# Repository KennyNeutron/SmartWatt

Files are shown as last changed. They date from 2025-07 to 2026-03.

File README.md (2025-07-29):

# SmartWatt

SmartWatt is a distributed smart energy limiter system designed to help households, boarding houses, and small businesses save on electricity costs. It uses a network of ESP32 microcontrollers and precision sensors to monitor and control multiple outlets, and automatically switches the main power source between grid, solar, or battery backup when a daily energy limit is reached.

## System Architecture

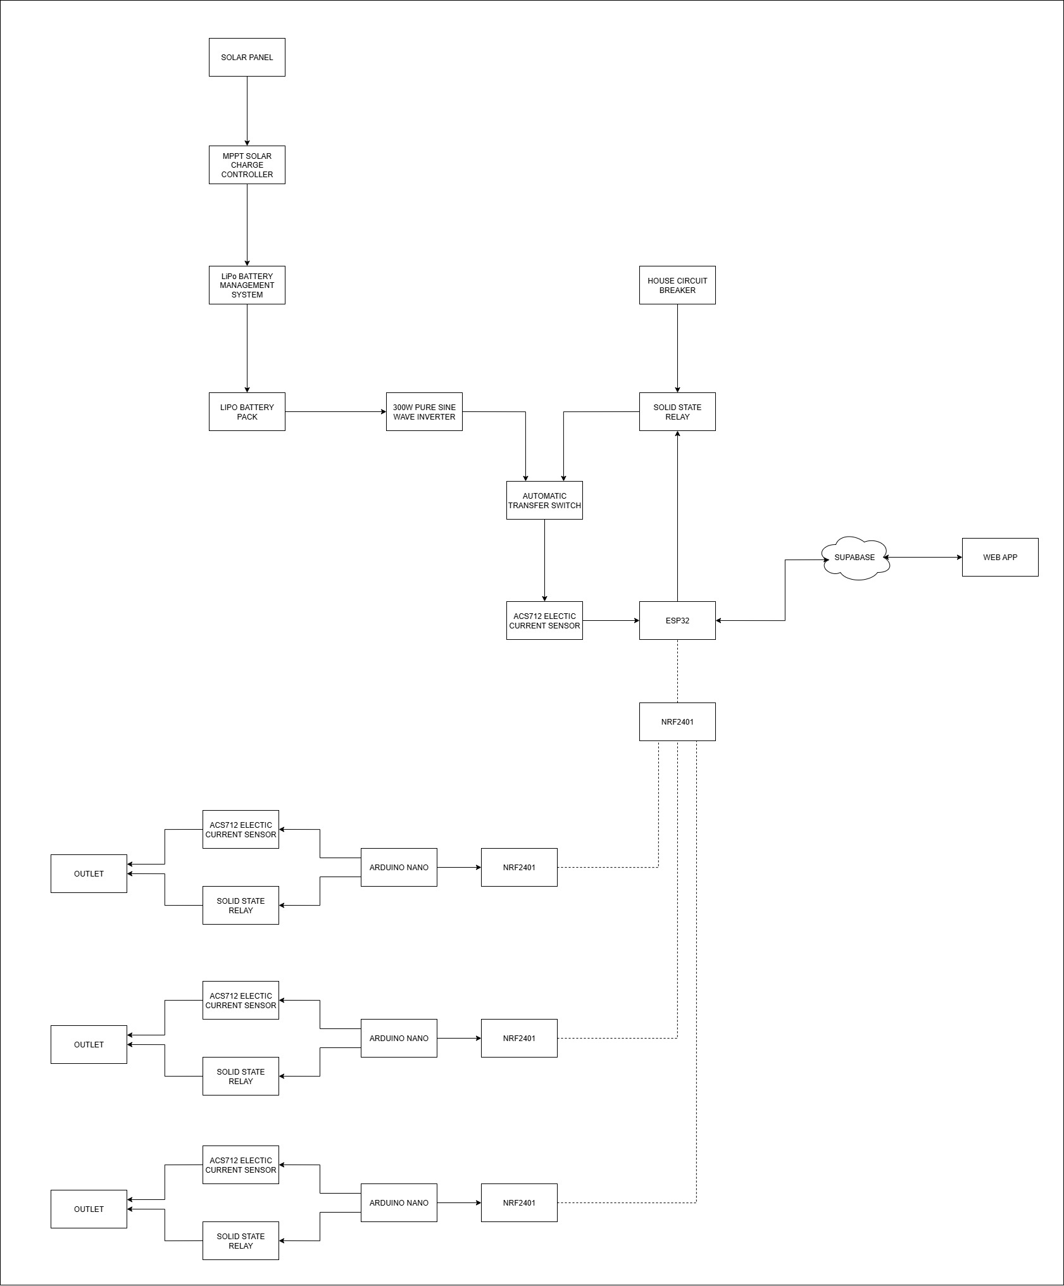
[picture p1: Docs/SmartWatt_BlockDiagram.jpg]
Block Diagram


1. **Solar & Battery Subsystem**

   - **Solar Panel** → **MPPT Solar Charge Controller** → **LiPo Battery Management System** → **LiPo Battery Pack**
   - **Pure Sine Wave Inverter** (300W) converts battery DC to AC.
   - **Automatic Transfer Switch (ATS)** chooses between inverter output and grid power.
   - **Solid State Relay (SSR)** connects the selected source to the house circuit breaker.

2. **Master Controller (ESP32)**

   - Reads total system current via ACS712 sensor.
   - Communicates daily energy usage and user settings to Supabase.
   - Forwards control commands to distributed outlet controllers via ESP-NOW.

3. **Distributed Outlet Controllers** (one per outlet)

   - **ESP32** monitors outlet current with an ACS712 sensor.
   - Controls outlet power via a dedicated SSR.
   - Joins the ESP-NOW mesh network to report usage and receive limit flags from the master controller.

4. **Cloud & Web Dashboard**
   - **Supabase** stores user accounts, settings, and energy logs.
   - **Web App** (hosted static site) provides secure login, live consumption dashboard, manual override, and monthly savings reports.

## Features

- **Per-Outlet Monitoring & Control**  
  Track and limit energy consumption at individual outlets.

- **Automatic Source Switching**  
  When the total daily kWh limit is reached, ATS and SSRs safely switch to solar/battery backup.

- **Distributed ESP-NOW Network**  
  Low-latency communication between the master ESP32 and outlet controllers without Wi‑Fi.

- **Secure Cloud Storage**  
  User profiles, limits, and usage logs are managed via Supabase.

- **Web-Based Dashboard**
  - Secure login
  - Set or adjust daily kWh limit
  - Real-time system and per‑outlet consumption
  - Manual override of grid or solar/battery source
  - Monthly savings report

## Hardware Components

- Solar panel and MPPT charge controller
- LiPo battery pack with BMS
- 300W pure sine wave inverter
- Automatic Transfer Switch (ATS) module
- Solid State Relays (SSRs) for system and each outlet
- ACS712 current sensors (system and per outlet)
- ESP32 microcontrollers (master and distributed controllers)
- Standard house wiring and circuit breaker panel

## Software & Cloud

- **ESP32 Firmware**

  - Master node: system monitoring, Supabase sync, ESP-NOW master
  - Outlet nodes: per-outlet monitoring and SSR control

- **Supabase**

  - PostgreSQL database for users, settings, and logs
  - Auth for secure login
  - Storage (optional) for graphs or logs

- **Web App**
  - Static React (or framework of choice) application
  - Connects to Supabase via its JavaScript SDK

## Installation & Deployment

1. Flash ESP32 firmware to master and outlet controllers.
2. Assemble hardware following the block diagram.
3. Configure Supabase project:
   - Create tables: `users`, `settings`, `system_logs`, `outlet_logs`.
   - Set up Auth and policies.
4. Deploy web app to any static host (Netlify, Vercel, GitHub Pages).
5. Enter Supabase project URL and key in the web app configuration.

## Configuration

- **Daily kWh Limit**: Set in the Settings page of the dashboard.
- **Manual Override**: Select grid or solar/battery source from the live dashboard.
- **Outlet Enable/Disable**: Toggle individual outlets on the dashboard.

## Contributing

1. Fork the repository.
2. Create a branch (`git checkout -b feature/your-feature`).
3. Commit changes (`git commit -m "Add feature"`).
4. Push (`git push origin feature/your-feature`).
5. Open a Pull Request.

## License

This project is licensed under the [MIT License](LICENSE).

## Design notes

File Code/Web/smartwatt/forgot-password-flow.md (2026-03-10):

# SmartWatt - Forgot Password Flow

This document outlines the architecture and user flow for the "Forgot Password" feature implemented in the SmartWatt web application.

## Overview

We use **Supabase Authentication** to handle the secure password reset process. Instead of emailing a reset link that the user must click (which can be problematic with certain email clients or if opened on a different device), we utilize an **OTP (One-Time Password) / 6-digit PIN code** flow.

When the OTP is verified successfully, Supabase securely logs the user in, giving them the necessary session to update their password on the `/reset-password` page.

## Detailed Flow

### 1. Request OTP (Email Step)

- **Location:** `/forgot-password` (Step 1)
- **Action:** The user enters their email address and clicks "Send Code".
- **Under the hood:**
  The client component calls `supabase.auth.signInWithOtp()` with the `shouldCreateUser: false` option. This ensures that a 6-digit OTP is sent only if the email belongs to an existing registered user.
- **UI Feedback:** A success message "Code sent! Check your email." is displayed, and the UI shifts to the Verification step.

### 2. Verify OTP (Verification Step)

- **Location:** `/forgot-password` (Step 2)
- **Action:** The user enters the 6-digit code received in their email.
- **Under the hood:**
  The component calls `supabase.auth.verifyOtp({ email, token: otp, type: "email" })`.
  If the OTP matches, the Supabase client successfully authenticates the user and creates an active session.
- **UI Feedback:** Upon success, the UI displays "Verified! Redirecting..." and routes the user to `/reset-password`.

### 3. Set New Password

- **Location:** `/reset-password`
- **Prerequisite:** The user must be authenticated (which they are, having just verified the OTP).
- **Action:** The user enters a new password and confirms it.
- **Under the hood:**
  The page calls `supabase.auth.updateUser({ password: newPassword })` to securely overwrite the existing password.
- **UI Feedback:** The user receives a success message ("Password updated successfully! Redirecting...") and is redirected to the `/login` page, or straight to `/home` depending on internal application logic.

## Why OTP instead of a Magic Link?

1. **Seamless Cross-Device Experience:** A user can request the code on their mobile app/desktop, check their email on another device, and type the 6-digit code back on the original device without losing their place.
2. **Reduced Email Provider Issues:** Some strict enterprise email clients "pre-fetch" or automatically click links in emails to scan them for malware, which can accidentally consume single-use magic links before the user clicks them.
3. **Better UX:** Keeps the user within the original tab/app rather than bouncing them out to their email client and back in a new tab.

## Relevant Files

- `src/app/forgot-password/page.tsx` - Email and OTP request & verification UI.
- `src/app/reset-password/page.tsx` - The actual password update component.
- `src/lib/supabase/client.ts` - The Supabase client initialization.

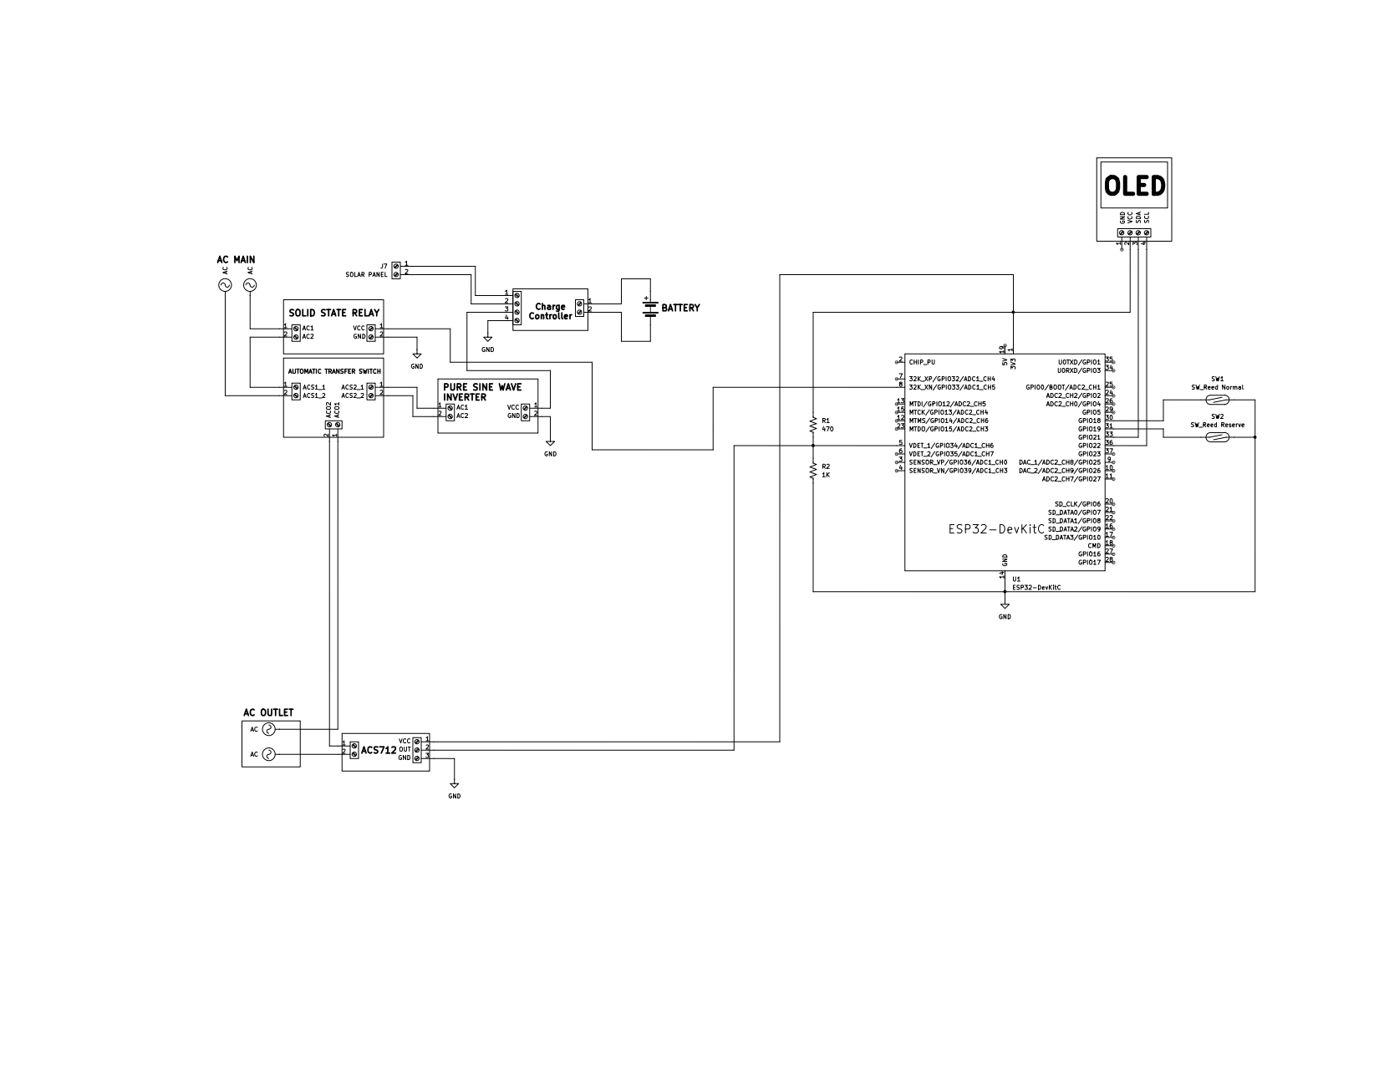
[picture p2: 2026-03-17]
Docs/Diagram V2/Smartwatt Schematic V2_page-0001.jpg

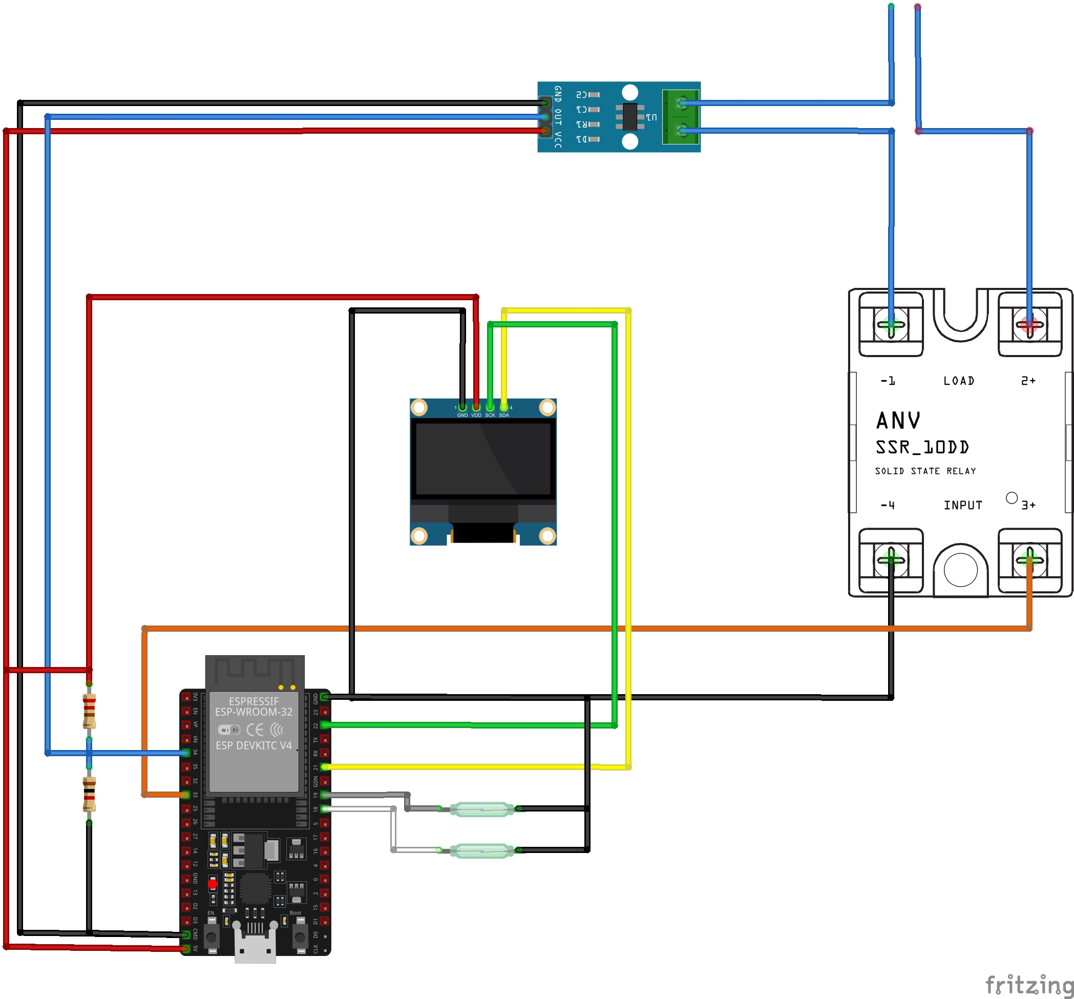
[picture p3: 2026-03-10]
Docs/Diagram V2/SmartWatt Fritzing V2_bb.jpg

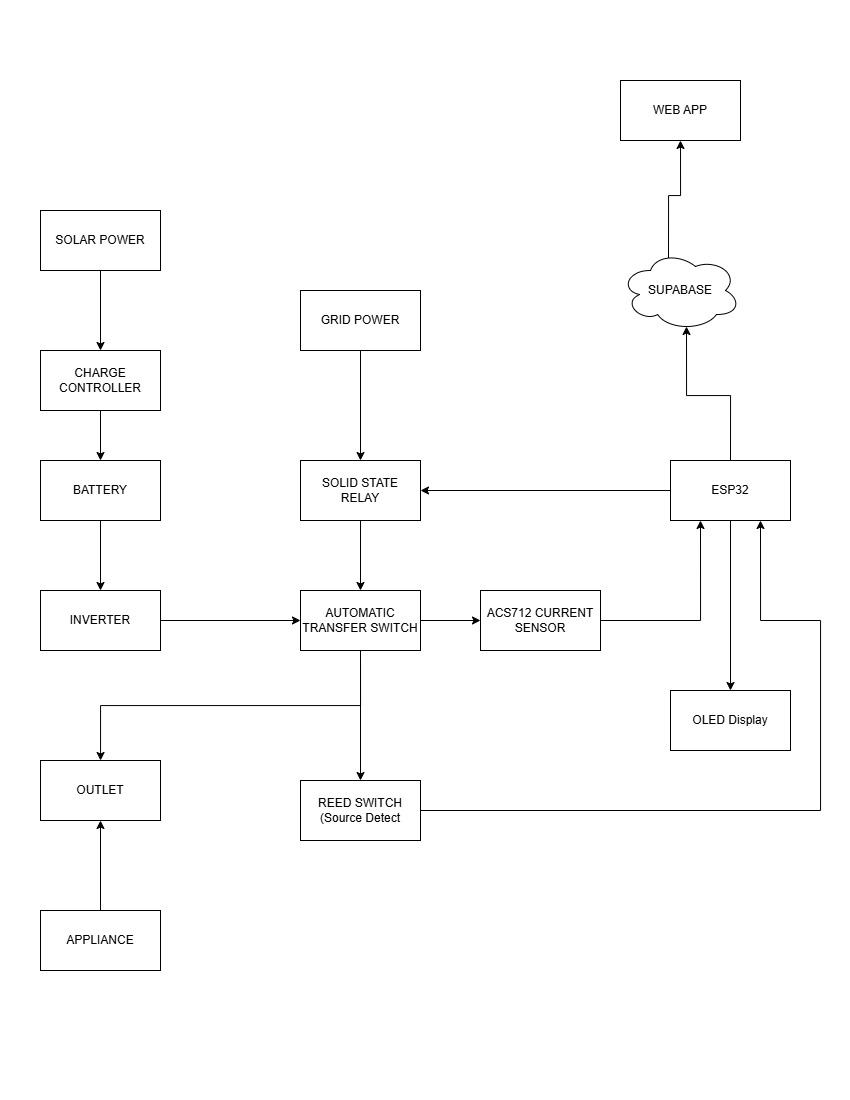
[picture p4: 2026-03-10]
Docs/Diagram V2/Smartwatt Block Diagram V2.jpg

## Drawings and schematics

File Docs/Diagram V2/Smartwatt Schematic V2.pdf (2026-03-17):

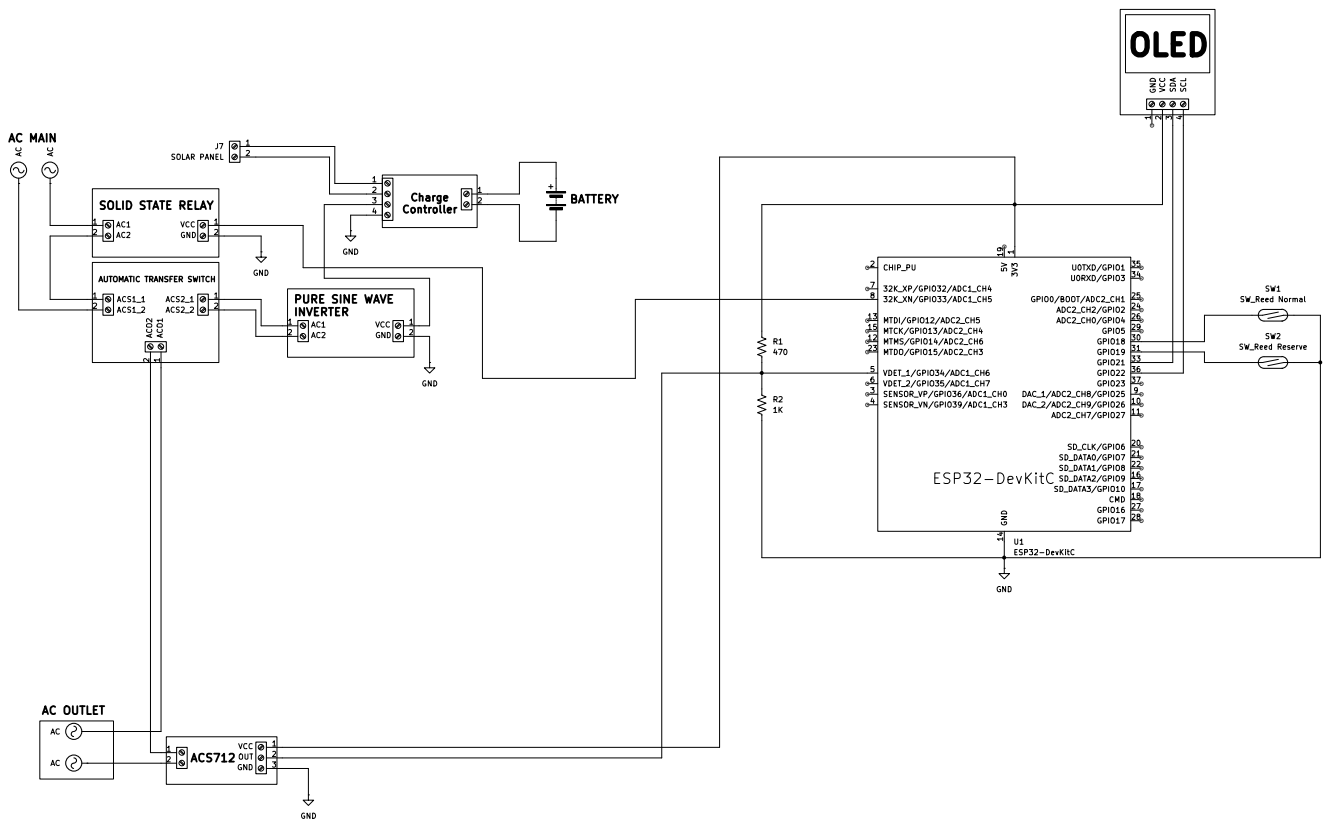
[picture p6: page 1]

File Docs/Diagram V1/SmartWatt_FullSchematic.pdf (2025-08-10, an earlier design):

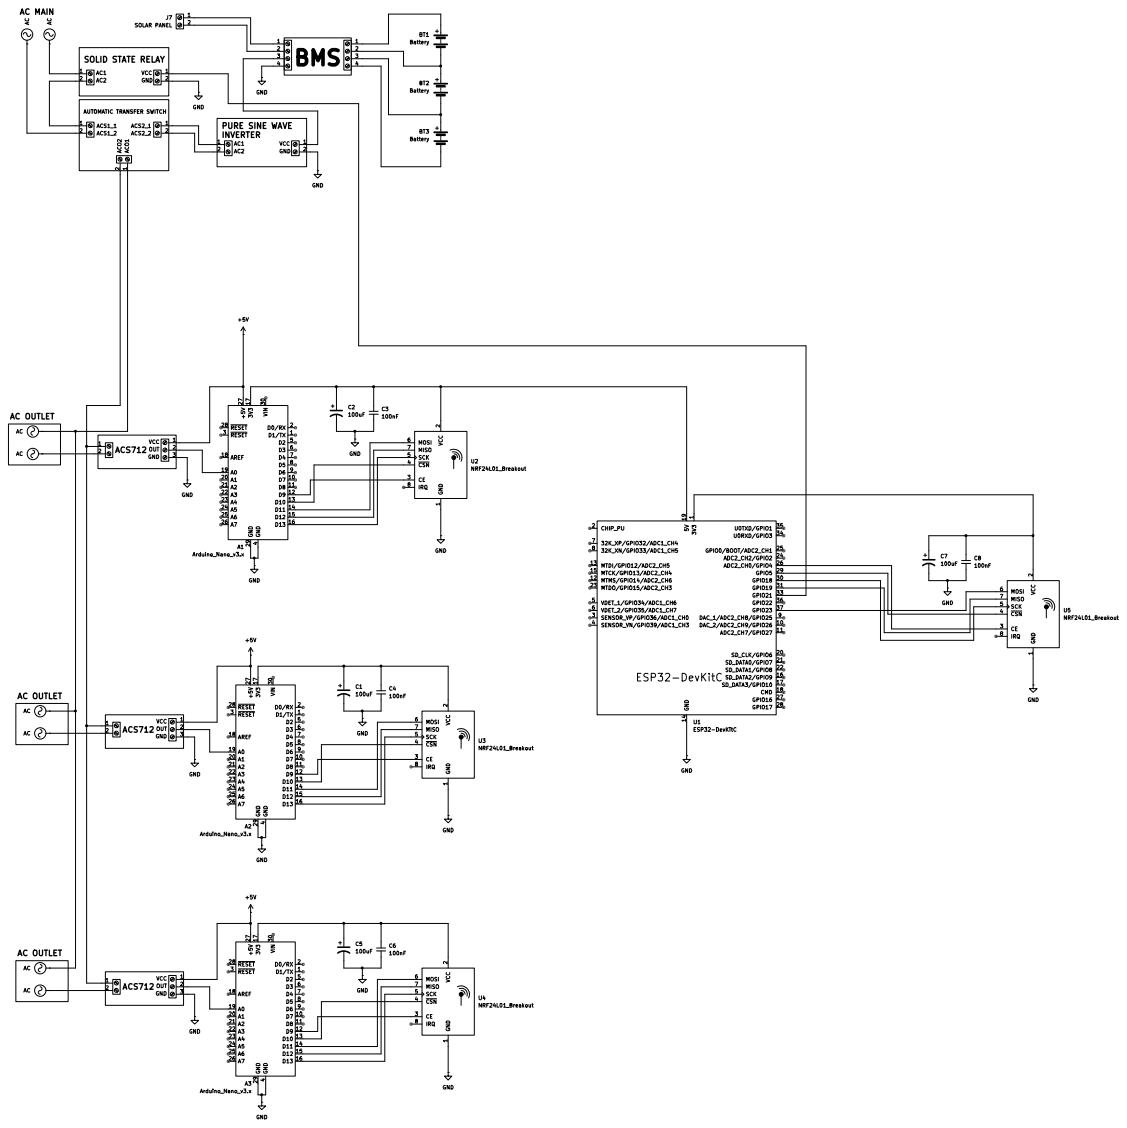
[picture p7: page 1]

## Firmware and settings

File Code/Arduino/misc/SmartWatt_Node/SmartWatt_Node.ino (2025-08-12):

/*
  SmartWatt Node v1.0.0
  Environment:           Arduino Nano/Uno
  Author:                
  Date Started:          2025-08-11
  Pin Usage:
    Current Sensor (ACS712):
      OUT   - A0 (Analog Pin 0)
      VCC   - 5V
      GND   - GND
    NRF24L01:
      CE    - GPIO9
      CSN   - GPIO10
      SCK   - GPIO13
      MOSI  - GPIO11
      MISO  - GPIO12
      VCC   - 3.3V
      GND   - GND
  Board Settings:
    Board:                     Arduino Nano
    Port:                      COM3
    Processor:                 ATmega328P (Old Bootloader)
    Programmer:                AVRISP mkII
  Features:
    - Current measurement with ACS712 sensor
    - Automatic offset calibration
    - Threshold filtering (ignores values < 0.1A)
    - Current display in mA and A (2 decimal places)
    - Wireless data transmission via NRF24L01
    - Real-time serial monitoring
*/

#include <SPI.h>
#include <nRF24L01.h>
#include <RF24.h>

// CE and CSN pins
RF24 NRF(9, 10);  // CE, CSN
byte address[6] = "SWD25";

// Data structure matching SmartWatt Node
struct __attribute__((packed)) SmartWatt_Data {
  uint8_t deviceID;
  uint16_t currentConsumption; // Use unsigned for mA
};


SmartWatt_Data smartwattData;

const int sensorPin = A0;
const float sensitivity = 0.066;  // V/A (0.100 for 20A module, 0.066 for 30A, 0.185 for 5A)
const float Vref = 5.0;
const float minCurrentThreshold = 0.1;  // Minimum current threshold to consider valid

float offsetVoltage = 2.5;  // Typical midpoint (sensor output with no current)

void setup() {
  Serial.begin(9600);

  smartwattData.deviceID = 0x01;
  smartwattData.currentConsumption = 0;

  // Debug print
  Serial.print("Device ID: 0x");
  Serial.println(smartwattData.deviceID, HEX);

  // Take an initial reading to determine offset voltage (zero current)
  long sum = 0;
  for (int i = 0; i < 100; i++) {
    sum += analogRead(sensorPin);
    delay(5);
  }
  offsetVoltage = (sum / 100.0) * (Vref / 1023.0);

  Serial.print(F("Calibrated Offset Voltage: "));
  Serial.println(offsetVoltage, 3);

  //Try to initialize NRF module for 5 seconds
  while (!NRF.begin()) {
    Serial.println(F("NRF24L01 Module not responding! Retrying..."));
    delay(1000);
  }
  Serial.println(F("NRF24L01 Module initialized successfully."));

  NRF.setPALevel(RF24_PA_MAX);
  NRF.setDataRate(RF24_250KBPS);
  NRF.openWritingPipe(address);
}

void loop(){
    int rawValue = analogRead(sensorPin);
  float voltage = (rawValue * Vref) / 1023.0;
  float current = (voltage - offsetVoltage) / sensitivity;

  // Apply threshold filter but keep as float
  float processedCurrent = 0.0;
  if (abs(current) >= minCurrentThreshold) {
    processedCurrent = current;  // Keep as float, no rounding
  }

  // Convert to mA using uint16_t and abs()
  smartwattData.currentConsumption = (uint16_t)(abs(processedCurrent) * 1000);

  Serial.print(F("Raw ADC: "));
  Serial.print(rawValue);
  Serial.print(F(" | Voltage: "));
  Serial.print(voltage, 3);
  Serial.print(F(" V | Current: "));
  Serial.print(smartwattData.currentConsumption);
  Serial.print(F(" mA ("));
  Serial.print(smartwattData.currentConsumption / 1000.0, 2);  // Display in A with 2 decimal places
  Serial.println(F(" A)"));

  // Send processed data via NRF
  NRF.write(&smartwattData, sizeof(smartwattData));
  Serial.println("Data sent successfully.");
  delay(1000);
}

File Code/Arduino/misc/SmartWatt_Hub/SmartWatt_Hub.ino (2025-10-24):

/*
  SmartWatt Receiver v1.0.0
  Environment:           ESP32 Dev Module
  Author:                
  Date Started:          2025-08-11
  Pin Usage:
    NRF24L01:
      CE    - GPIO4
      CSN   - GPIO5
      SCK   - GPIO18
      MOSI  - GPIO23
      MISO  - GPIO19
      VCC   - 3.3V
      GND   - GND
  Board Settings:
    Board:                     ESP32 Dev Module
    Port:                      COM3
    CPU Frequency:             240 MHz (WiFi/BT)
    Core Debug Level:          None
    Erase Flash Before Upload: Disabled
    Events Run On:             Core 1
    Flash Frequency:           80 MHz
    Flash Mode:                QIO
    Flash Size:                4 MB (32 Mb)
    JTAG Adapter:              Disabled
    Arduino Runs On:           Core 1
    Partition Scheme:          Default 4 MB w/ SPIFFS (1.2 MB APP / 1.5 MB SPIFFS)
    PSRAM:                     Disabled
    Upload Speed:              921600
    Zigbee Mode:               Disabled
  Features:
    - Wireless data reception via NRF24L01
    - SmartWatt Node data parsing
    - Real-time current monitoring display (2 decimal places)
    - Device ID identification
    - Connection status monitoring
*/

#include <SPI.h>
#include <nRF24L01.h>
#include <RF24.h>
#include <U8g2lib.h>

// NRF24L01 pins for ESP32
RF24 NRF(4, 5);  // CE, CSN
byte address[6] = "SWD25";

U8G2_SH1106_128X64_NONAME_F_HW_I2C u8g2(U8G2_R0, /* reset=*/U8X8_PIN_NONE);

// Data structure matching SmartWatt Node
struct __attribute__((packed)) SmartWatt_Data {
  uint8_t deviceID;
  uint16_t currentConsumption; // Use unsigned for mA
};


SmartWatt_Data smartwattData;

unsigned long lastDataReceived = 0;
const unsigned long dataTimeout = 5000;  // 5 seconds timeout

void setup() {
  Serial.begin(115200);
  u8g2.begin();
  Serial.println("SmartWatt Receiver Starting...");
  Serial.println("===============================");

  // Initialize NRF24L01
  if (!NRF.begin()) {
    Serial.println("ERROR: NRF24L01 Module not responding!");
    while (1) {
      delay(1000);
      Serial.println("Retrying NRF24L01 initialization...");
      if (NRF.begin()) {
        break;
      }
    }
  }
  Serial.println("NRF24L01 Module initialized successfully.");

  // Configure NRF24L01
  NRF.setPALevel(RF24_PA_MAX);
  NRF.setDataRate(RF24_250KBPS);
  NRF.openReadingPipe(0, address);
  NRF.startListening();

  Serial.println("Receiver ready. Waiting for SmartWatt Node data...");
  Serial.println("Format: [Device ID] | Current: XX.XX A | (Raw mA: XXX) | Status");
  Serial.println("=============================================================");
}

void loop() {


  display_Main();

  // Check if data is available
  if (NRF.available()) {
    // Read the data
    NRF.read(&smartwattData, sizeof(smartwattData));
    lastDataReceived = millis();

    // Display device ID
    Serial.print("[0x0");
    Serial.print(smartwattData.deviceID, HEX);

    // Debug: Show raw milliamp value
    Serial.print("] Raw mA: ");
    Serial.println(smartwattData.currentConsumption);
  }

  // Check for communication timeout
  if (millis() - lastDataReceived > dataTimeout && lastDataReceived > 0) {
    Serial.println("WARNING: No data received for 5 seconds!");
    Serial.println("Check SmartWatt Node connection and power.");
    Serial.println("Waiting for data...");
    lastDataReceived = 0;  // Reset to avoid repeated warnings
  }

  delay(100);  // Small delay to prevent overwhelming serial output
}

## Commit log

2025-08-05 added files for the schematic/wiring diagram of the system (by parts)
    [SmartWatt.fzz]
2025-08-10 added KiCAD files for the full schematic diagram of the project (as one)
    [SmarWatt.kicad_pcb, SmarWatt.kicad_sch]
2025-08-10 updated fritzing files and block diagram for the comm adjustment to NRF24L01 from ESPNOW
    [SmartWatt.fzz]
2025-08-11 added NRF24L01-to-ArduinoNano test code
2025-08-12 fixed data transmission for the Hub and Node
    [SmartWatt_Hub.ino, SmartWatt_Node.ino]
2025-08-12 can now transmit current data from node(with address: 0xHH) and receive it to the hub with display on OLED display
2025-08-12 fixed the error in the datastructure and optimized the oled display
    [Display.ino, SmartWatt_Hub.ino, SmartWatt_Node.ino]
2025-11-17 feat: enlarge SmartWatt login layout and logo frame
2025-11-18 feat: update dashboard to show grid/solar usage and device id
2025-11-19 feat: add SmartWatt about, settings, power limiter and monthly report pages
2025-11-26 added supabase test code for the esp32
2025-11-27 working supabase test on esp32 and updated home page to fetch the latest data
2025-11-27 added code for the main device (can now connect to wifi and display wifi status to OLED Display)
2025-11-27 device settings update(web app) and fetch(esp32) is now working
2025-11-27 fixed: trying to fix the NTP sync error on the ESP32 (not fully fixed yet)
    [Display_Home.ino, SmartWatt_Device.ino, Variables.h]
2025-12-02 feat: integrate supabase types and update device firmware
    Web:
    - Add database.types.ts for full schema type definitions.
    - Update Supabase client and server to use Database generic for type safety.
    - Fix column name mismatch (hardware_id -> manufacturer_id) in Home dashboard.
    Arduino:
    - Add ACS712 current sensor implementation and test code.
    - Update display logic for Home and WiFi screens.
    - Refactor device variables and main logic.
    [Display_Home.ino, Display_WiFi.ino, ESP32_ACS712_TEST.ino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]
2025-12-02 fix: update power-limiter to use manufacturer_id
    Replace deprecated 'hardware_id' column reference with 'manufacturer_id' in the power-limiter page to match the database schema and fix build errors.
2025-12-02 feat: Initialize SmartWatt device with OLED display, ACS712 sensor, WiFi connectivity, and remote configuration fetching.
2025-12-03 feat: Introduce SmartWatt device core with ACS712 current sensing and essential configurations.
2025-12-03 feat: Add initial SmartWatt device firmware for current sensing, Supabase data logging, and web UI for power monitoring. (Working so far)
2025-12-03 feat: Implement initial SmartWatt device firmware for display, sensor data collection, Supabase communication, and a new web home page.
2025-12-04 feat: Add dashboard with real-time power data display and new pages for monthly reports and power limiter.
2025-12-10 fixed lints for deployment
    [AC712_Test.ino, Display.ino, ESP32_ACS712_TEST.ino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]
2026-02-03 feat: Implement ACS712 current sensing module with calibration, RMS current, power, and energy tracking.
2026-02-08 feat: implement settings page with device and dashboard preferences, including save functionality.
2026-02-09 feat: Add power limiter page allowing users to view and set daily energy consumption limits for their devices.
2026-02-10 Implements monthly report export to CSV/PDF
    Adds the ability to export monthly report data to CSV and PDF formats.
    This allows users to download their energy consumption data for further analysis and record-keeping.
    It includes the necessary libraries for PDF generation and data formatting for CSV export. Also adjusts limits for power configuration.
2026-02-15 Implements password recovery flow
    Adds "Forgot Password" functionality, including:
    - A new "Forgot Password" page allowing users to request a password reset link.
    - A new "Reset Password" page where users can set their new password.
    - An error page to handle invalid or expired password reset links.
    - Integration with Supabase auth to send password reset emails.
2026-02-15 Implements OTP verification for password reset
    Updates the password reset flow to use OTP (One-Time Password) verification instead of a direct reset link.
    This enhances security by verifying the user's email address before allowing a password reset.
    The changes include:
    - Sends an OTP to the user's email upon request
    - Implements a new step to verify the OTP
    - Redirects to the password reset page after successful verification
2026-02-15 Updates displayed power calculation
    Updates the power display to show Watts instead of Amps.
    The display now correctly shows power consumption by multiplying the current by the voltage (assumed to be 230V).
    [Display_Home.ino]
2026-02-21 Adds daily energy reset functionality
    Implements a daily reset for energy consumption data.
    This ensures that energy usage is tracked on a daily basis,
    resetting at midnight to provide accurate daily readings.
    [ACS712.ino, Display_Home.ino, Variables.h]
2026-03-10 Introduces OTP password reset and improves report data
    * Documents the new "Forgot Password" flow, utilizing Supabase Authentication with a secure OTP (One-Time Password) / 6-digit PIN code system. This enhances user experience by offering a seamless cross-device flow and mitigating issues commonly associated with magic links.
    * Enhances monthly report data fetching by prioritizing the retrieval of the latest device readings. This addresses the Supabase REST API's default row limit by fetching data in reverse chronological order with an increased limit, then reversing it for correct processing, ensuring all recent data is included.
    * Adjusts the `MAX_POWER_KW` threshold for anomaly det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
2026-03-10 updated diagrams to v2
    [SmarWatt.kicad_pcb, SmarWatt.kicad_sch, SmartWatt Fritzing V2.fzz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]
2026-03-17 Enhances kWh data precision and updates schematic
    Improves the accuracy of energy consumption values displayed throughout the web application and in monthly report exports. All kWh readings, including dashboard metrics, monthly summaries, daily brea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
    Updates the Smartwatt V2 schematic to reflect changes in the power management section. Renames the 'BMS' component to 'Charge Controller', adds a 'BATTERY' label for clarity, refines battery connecti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
    [Smartwatt_Schematic_V2.kicad_sch]
